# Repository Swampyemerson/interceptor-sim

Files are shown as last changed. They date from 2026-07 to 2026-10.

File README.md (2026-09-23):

# Counter-UAS Interceptor — Sim-Proven Guidance, Real Build In Progress



A quadcopter interceptor that catches a moving target with its own camera.
The **ruled engagement (ADR-0103/0105) is a chase-only pursuit**: cued once
at the trigger by a GPS relay (latched, link dead after launch — **no
datalink in flight**), it flies a belief rendezvous to behind the target and
closes on camera measurements. The earlier **coded open-loop dash +
pro-nav terminal** remains the flying default only until a Gazebo
cross-check passes. Guidance was built and validated across a 107-ADR
measured campaign in **PX4 SITL + Gazebo Harmonic** plus a purpose-built
flight-code-in-the-loop Monte-Carlo simulator; the physical interceptor is
**on the bench** (motors soldered, flight-controller pack verified on-board,
Pi-to-Pixhawk OFFBOARD proven props-off).

<p align="center">
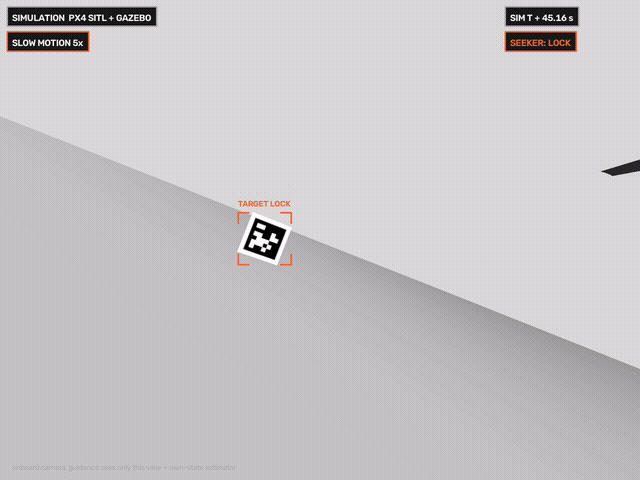
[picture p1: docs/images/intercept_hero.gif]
Onboard seeker view of a simulated intercept, slow-motion terminal, closest approach 0.413 m
  
</p>
<p align="center"><sub>Onboard seeker view, simulation (PX4 SITL + Gazebo). Closest
approach 0.413 m against a 2 m/s crosser; retiming labeled on-screen; the
0.35 m contact bar is still open. Log: <code>logs/m4_intercept_pronav_20260923T025539Z.csv</code>.</sub></p>

**Status at a glance** (each row traces to the contract):

| | |
|---|---|
| Ruled design | chase-only pursuit (ADR-0103/0105); dash + pro-nav stay the flying default — the Gazebo cross-check **failed its registered bar** (below), so the swap is blocked |
| Flight-code port | matches its prototype in the fast sim (100% of 50 nominal runs ≤ 0.35 m, median 0.068 m); in Gazebo it chases camera-driven but closes only to median 1.51 m — **simulation, transfer gap open** |
| Not yet done | no camera-guided intercept inside the 0.35 m contact bar in Gazebo; no real-world intercept |
| Hardware | bench build under way; Pi 5 seeker measured 96.6 fps (AprilTag pipeline) |
| Honesty machinery | ground truth firewalled from guidance (AST-enforced); assumptions register grades every given input |

This is a portfolio project for aerospace internship applications. The claim
discipline is the point: every number below traces to a committed log, a gate
script, or an ADR in [`docs/decisions.md`](docs/decisions.md) — and the
project's retractions are documented with the same care as its wins, because
**the negative results are load-bearing**. The honest resume line:

> *"Camera-only terminal guidance validated by Monte-Carlo miss statistics in
> PX4/Gazebo SITL and a flight-code-in-the-loop simulator; ported the ruled
> pursuit terminal into the flight software to numeric parity with its
> prototype (100% of 50 seeded runs inside the 0.35 m contact radius, median
> 0.068 m, simulation); quantified the perception acquisition envelope and
> the flight-dynamic detector-recall limit."*

<p align="center">
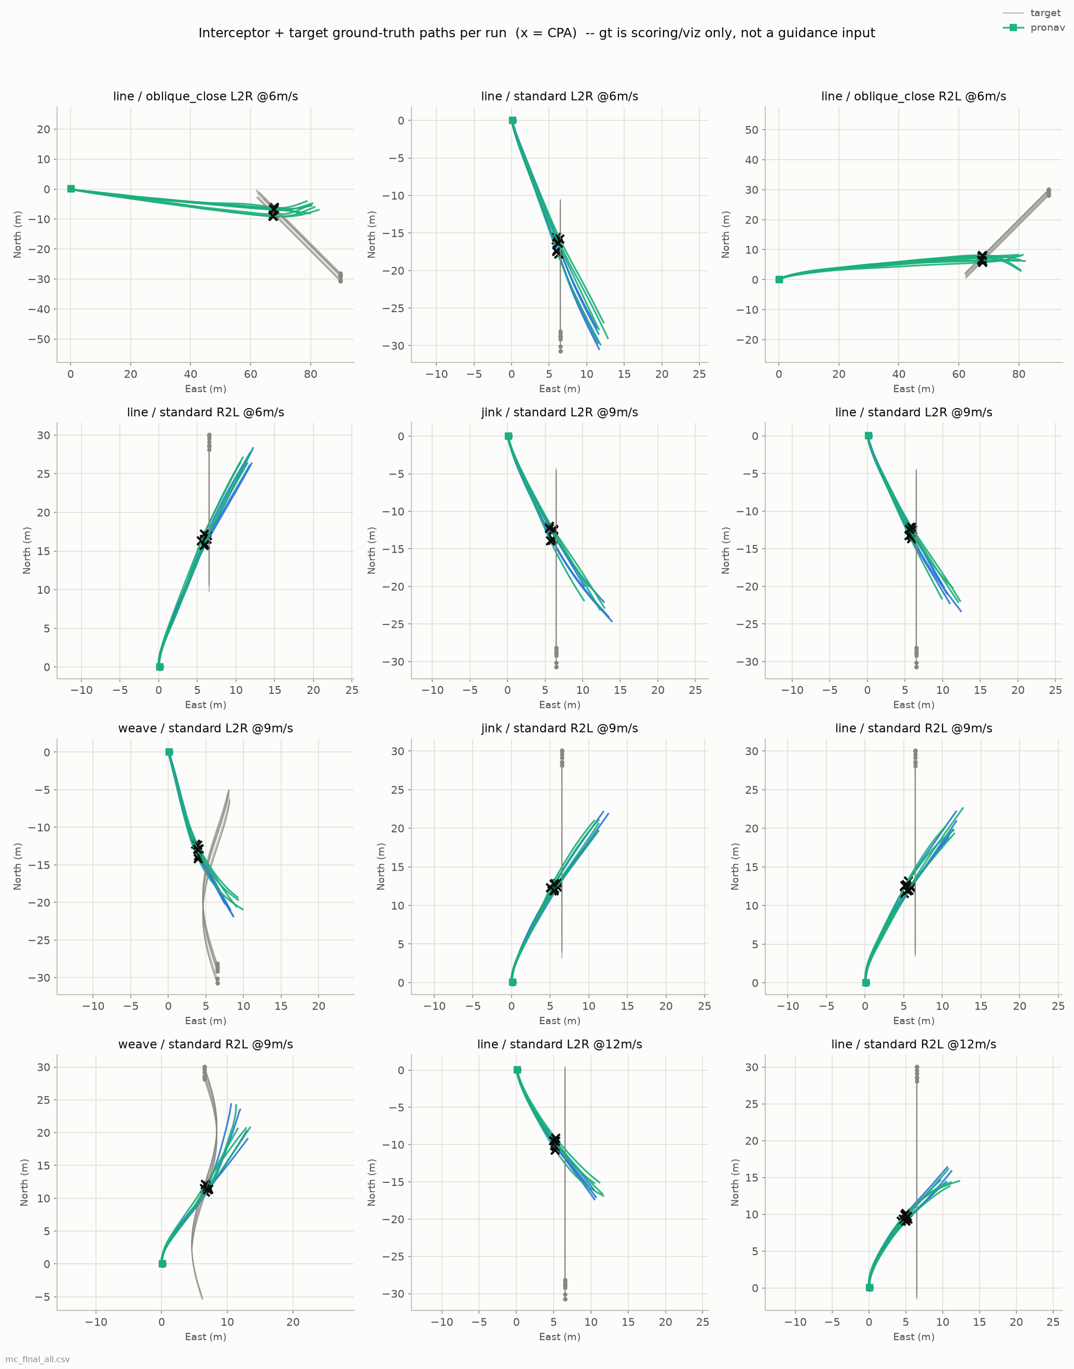
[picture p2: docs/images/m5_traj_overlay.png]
M5 Monte-Carlo trajectory overlay
  
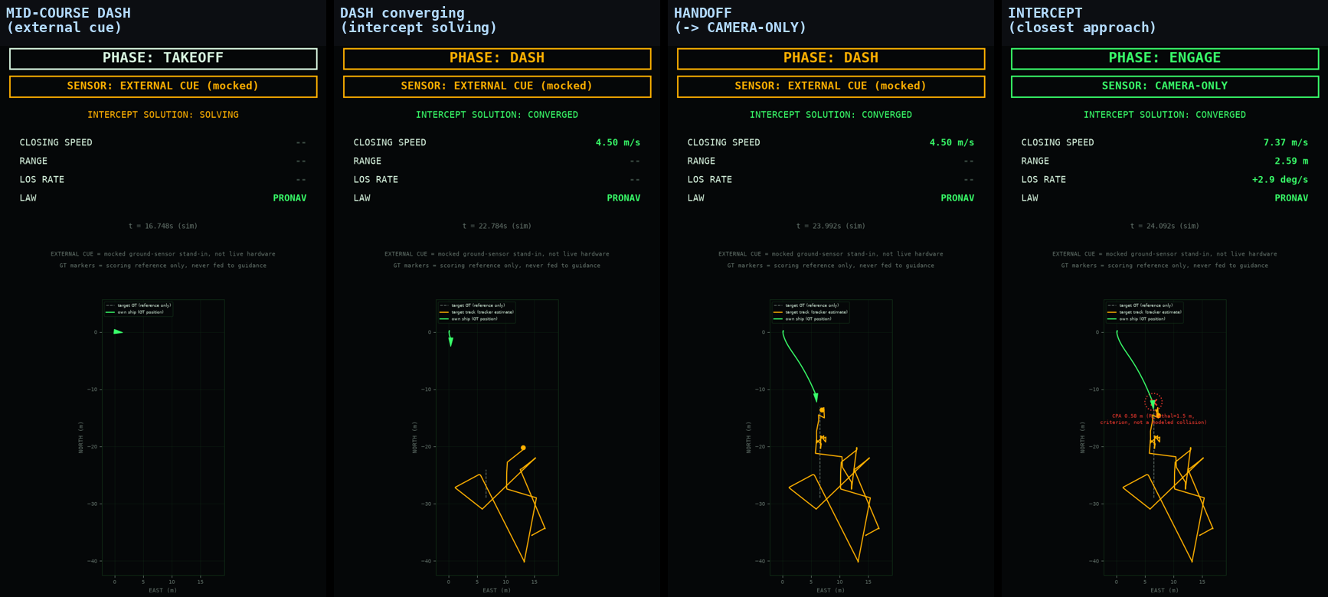
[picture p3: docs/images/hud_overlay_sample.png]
Seeker HUD overlay at handoff
  
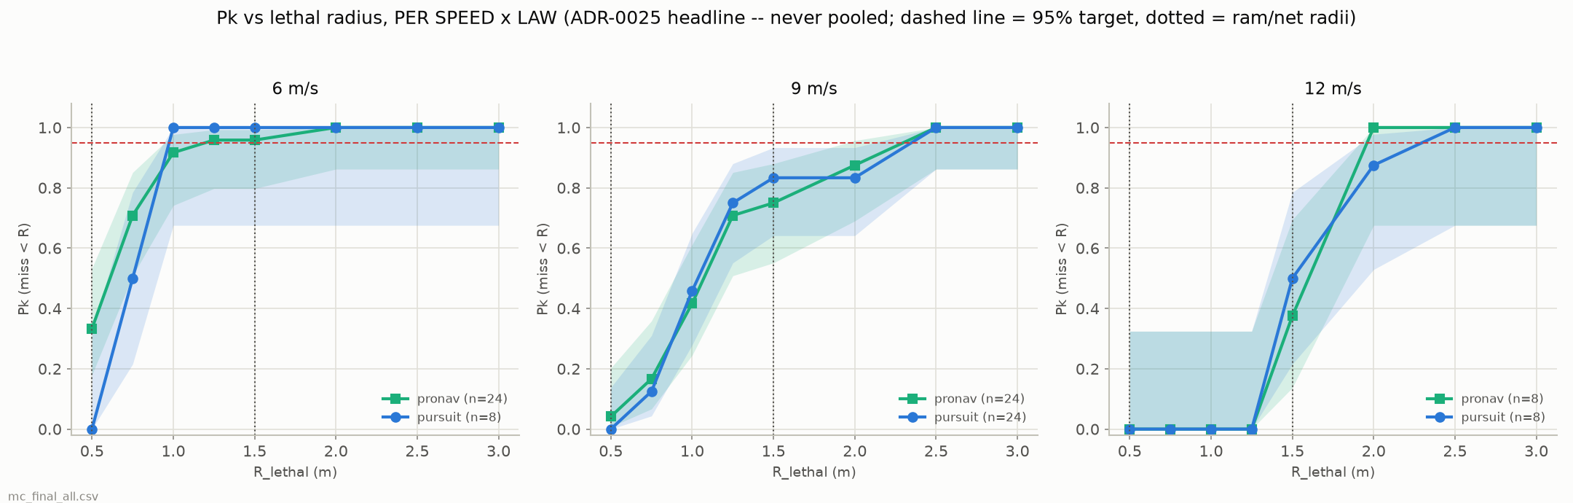
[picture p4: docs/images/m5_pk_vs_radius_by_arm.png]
Pk vs lethal radius, per speed and law
  
</p>

**Canonical live state:** [`docs/project_state.json`](docs/project_state.json)
— the machine-readable contract (stage statuses, hard constraints, a
contradiction ledger, a dead-ideas graveyard, an assumptions register) —
rendered to [`docs/dashboard.html`](docs/dashboard.html) and the generated
MBSE views ([`docs/mbse.html`](docs/mbse.html)). Where anything in this README
and that contract disagree, **the contract wins**. Mission and scope history:
[`docs/goals.md`](docs/goals.md); milestone roll-up:
[`docs/progress.md`](docs/progress.md); working front:
[`docs/next.md`](docs/next.md).

**Read "What is proven / what is not" before the results table.** Several
headline-looking numbers from this project's own history were retracted by
its own audits; this README quotes only what survived. The long form of every
table caveat: [`docs/results_notes.md`](docs/results_notes.md).

---

## Current mission (the real build)

**A cued interceptor hits a moving target flying ≥9 m/s (20 mph), outdoors,
camera-only terminal, no datalink after launch.** The ruled engagement is
chase-only pursuit (ADR-0103/0105); the coded dash + stock pro-nav remain the
flying default only until the Gazebo cross-check passes. Success is a
**binary kill** (contact), confirmed by seeker video + phone slow-motion +
both aircraft flight logs — deliberately *not* a measured sub-meter CPA (the
RTK metrology pair was cut with the 2026-07-15 binary-kill re-scope). The
**first kills fly the AprilTag seeker** (96.6 fps measured on the Pi 5 CPU);
the markerless seeker is the end-state — the real-data retrain `n-mono`
(AP50 0.44 held-out) is the hardware default for that phase, pending the
Hailo NPU, and it never reads the tag. Source: `docs/project_state.json`
(goal), `docs/real_build_coded_dash.md`, `docs/hardware_order_list.md` §0b/§0c.

Hard constraints (full list + evidence in the contract): **no guidance
datalink after launch** (the GPS cue is latched at the trigger and the link
is dead from then on; the RC link is kill/arm only — jam resistance by
architecture, not protocol); **wide FoV (~100°) non-negotiable** (ADR-0024;
the ±30° figure it protected is a dash-era acquisition envelope); **prop
clearance is a geometry problem**, not a software one.

---

## What is proven, and what is not

**Proven (gated, committed evidence):**

- **The guidance law and loop.** Pro-nav (`a = N·Vc·λ̇`, N=5) beats pursuit
  4.6–7.6× on a 2 m/s crosser, camera-only (M4 gate); the two-stage
  dash→camera-terminal architecture holds to 12 m/s maneuvering targets
  against a cooperative (billboard/AprilTag-class) sensor picture. The
  portable [`flight/`](flight/) core (LOS derotation, alpha-beta estimation,
  pro-nav, undistortion, camera lever-arm) is pure math with its own test
  suite and no sim imports — it runs unchanged on the real Pi.
- **The methodology.** Paired seeds (n≥8), control arms, pre-registered
  verdict scripts, a numeric no-cheat audit on every guidance path, and a
  statistics-before-verdicts rule. This machinery caught every false
  positive below *before* it shipped.
- **The chase-only flight-code port.** The ruled pursuit terminal
  (`flight/pursuit_terminal.py`, a relative-state Kalman filter with
  capture-time attitude handling) runs through the unmodified flight state
  machine to **numeric parity with its prototype**: a registered tick-level
  trace found four coupled port defects, and the fixed port scores 100% of
  50 seeded nominal runs inside the 0.35 m contact radius, median 0.068 m
  (`isim/specs/parity_trace_2026-09-22.md`) — **simulation**. The
  pre-registered independent Gazebo cross-check then delivered both kinds of
  result: its shakedown flight caught a fifth port defect (a frozen Phase-A
  camera yaw, invisible to the isim grid, fixed and regression-pinned), and
  the scored n=8 **failed the registered bar** — the port chases
  camera-driven (46–67 detections consumed, zero aborts) but closes only to
  median 1.51 m vs the 0.122 m matched-optics prediction, so the
  default-terminal swap stays blocked and the transfer gap is the named next
  problem (`docs/xcheck_gazebo_pursuit_prereg.md`).

**Not proven — the honest wall (this is the interesting part):**

- **No camera-guided intercept of the realistic 3D quad target exists in the
  dataset.** When the flat billboard target was replaced with a proper 3D
  quad, a series of sub-meter "camera-guided" results were retracted as
  **open-loop dash-ballistics mirages** — a control arm with the camera
  contributing nothing scored the same (dash-only 0.30 m vs with-terminal
  0.29 m; ADR-0076 add #18g/#18h). Five such mirages were caught and
  retracted in that arc alone (ADR-0076; `docs/project_state.json`
  graveyard).
- **The binding wall is flight-dynamic detector recall, not guidance.** The
  deployed markerless detector reads **100% recall statically at 8–22 m**
  but **~0.8% on the approach in flight** (ADR-0076 add #18i/#18k). The
  un-eliminated mechanisms are ground-clutter background under the
  nose-down dash pitch and phantom competition — both sim-testable, both
  open. The dash pitches nose-down ~27–36° (median; ADR-0060), which parks
  a co-altitude target at the top of the frame; the pointing fix is a fixed
  up-tilt mount sized to the *measured* real dash pitch (build item, not
  yet validated).
- **The dash-era terminal had no vertical channel, and its miss was ~82%
  vertical** (ADR-0095/0099/0100): the fix arc moved sprint-only flights
  from 2/16 to 13/16 inside the contact radius — best case only (camera off,
  aim within ~±1° of optimum, target height known to ~0.1 m). The chase-only
  pursuit terminal steers all three axes; its own vertical behavior is what
  the current cross-check exercises. Full forensic history:
  [`docs/vertical_channel_analysis.md`](docs/vertical_channel_analysis.md).
- **"Works comms-denied" stays HELD** — see the box in the results section.

---

## Headline results (each traced; scope stated inline)

| Result | Number | Scope / caveat | Source |
|---|---|---|---|
| M0–M2 foundations (boot, camera, AprilTag detection) | detection rate 1.000, mean pose error 0.0861 m @ ~4.9 m | wide (99.7°) lens; sim lighting | gates `check_m0/1/2.sh`, 2026-07-04; `docs/progress.md` |
| M3 static intercept, hold 2 m standoff | final error **0.018 / 0.035 m** (bar < 0.5 m) | two verifier-confirmed runs | `scripts/check_m3.sh`; ADR-0008; committed `logs/m3_intercept_*.csv` |
| M4 pro-nav vs pursuit, 2.0 m/s crosser, camera-only | pro-nav **0.402 / 0.277 / 0.443 m** vs pursuit **2.544 / 2.109 / 2.048 m** | official gate-config runs; the dev-phase config selection that night is disclosed (ADR-0009 addendum; [notes](docs/results_notes.md#m4)) | `scripts/check_m4.sh`; ADR-0009; committed `logs/m4_intercept_*_20260705T03*.csv` |
| Two-stage handoff (S2), 6 m/s crosser | miss 1.1–2.3 m, handoff latches, honesty audits pass | proves the *architecture* (running start + structural handoff), not sub-meter precision; the S2 ground-stereo architecture is since retired | `retired/scripts/check_s2.sh`; ADR-0010/0013 |
| Why fast crossers miss ~1.4 m (41-flight forensics) | terminal correction capacity **½·a·t_go² ≈ 0.72 m** vs **1.69 m** already delivered at handoff → a perfect terminal camera cuts the miss only ~25% | miss tracks zero-effort-miss at handoff with r² = 0.96 — *variance explained*, not "96% of any one miss" | ADR-0023/0027; `retired/docs/terminal_diagnosis.md` |
| M5 final Monte-Carlo, n=96 (pursuit vs pro-nav × 6/9/12 m/s × line/maneuver/oblique) | **96.9% clean** (ran to completion and engaged; failures stay in every Pk denominator), mean miss 1.08 m, median 0.93 m; per-speed Pk per ADR-0025, never pooled | flew the **clean AprilTag sensor** (the disclosed perception upper bound), flat-board target; laws tied within the ~1 m run-to-run noise ([notes](docs/results_notes.md#m5)) | ADR-0036; `scripts/check_m5.sh`; committed `logs/mc_final_all.csv`; plots `docs/images/m5_*.png` |
| Markerless seeker v2 (kill the AprilTag) | false-detection pollution **0.751 → 0.000**, range honesty **0.056 → 0.935**; ~+1 m median miss vs the tag = bearing *quality* (box-center vs subpixel corners) | in-sim markerless; on real outdoor mono frames v2 scores **AP50 0.0003** (transfer bet lost) — the hardware seeker is the real-data retrain `n-mono` (AP50 0.44 held-out) | ADR-0038/0040/0042/0043; `scripts/check_seeker_v2.sh`; `logs/nn_tier/eval_n-mono_heldout.csv` |
| Chase-only flight-code port parity | port matches prototype: **100% of 50 seeded nominal runs ≤ 0.35 m, median 0.068 m**; aim-error 10°/20° cells 100%; target +2 m cell 68–76% (no-re-approach design gap) | **simulation** (flight-code-in-the-loop isim); a registered trace found and fixed 4+1 port defects — the fifth (a frozen Phase-A camera yaw) was caught by the Gazebo cross-check, invisible to the isim grid | ADR-0103/0105; `isim/specs/parity_trace_2026-09-22.md` |
| Gazebo cross-check of the chase (pre-registered, n=8) | camera-driven chase confirmed (46–67 detections/flight, 0 aborts) but CPA **0.55–2.33 m, median 1.51 m** — registered bar **FAILED**; default swap stays blocked | the honest transfer result: real EKF/control/latency dynamics cost ~1.4 m vs the fast sim's matched prediction (0.122 m); diagnosis next, not tuning | `docs/xcheck_gazebo_pursuit_prereg.md`; `logs/xcheck_gz_20260923_fixed/` |
| Detect-then-track maneuvering terminal (billboard era) | post-handoff camera-terminal Pk@2.5 m: weave **3/16 → 14/14**, jink **1/8 → 14/15** (paired n=16 baseline reads 3/15 → 14/15); phantom handoffs 12 → 0; zero gross (>8 m) false terminal detections (0/155) in the headline arm | one empty Gazebo world (disclosed); **the CSRT tracker was later dropped for the 3D quad target** — the deployed config is NN-only every frame (ADR-0076 add #2; [notes](docs/results_notes.md#t21)) | ADR-0058; committed `logs/mc_t21_*.csv`; `scripts/check_t21.sh` |
| Pk statistics hardening, n=72 | **Pk@2.8 m 72/72 — 95.0% Clopper-Pearson lower bound** (clears the ratified ≥95%-CI bar); Pk@2.5 m 71/72 = 98.6% point / 92.5% CP-LB | **flat-billboard target**, weave + 12 m/s only, never pooled, radius always stated; the 3D-quad target later exposed the wall this shape masked ([notes](docs/results_notes.md#pk72)) | ADR-0064/0025; committed `logs/mc_pk72_weave_s*.csv` |
| Perception wall, quantified | in-flight approach recall **0.8%** vs **100% static** at 8–22 m, same detector, same threshold | the wall is flight-dynamic (pointing + background + phantom competition), **not** range/resolution/aspect — each of those was tested and eliminated | ADR-0076 add #18i/#18k; `scripts/seeker/approach_recall.py` |
| Open-loop dash robustness | 48/48 flights still acquired/engaged with up to **±30° aim error** | dash-robustness only — *not* perception proof (ENGAGE streaks can be phantom, add #18g) | ADR-0076 add #18b/#18c |

> **Comms-denied status: HELD — tested, not merely untested.** The one-way
> handoff latch is real and structural: once the camera terminal latches, the
> cue channel is closed and unreadable, so a link jammed *after* handoff
> cannot touch the terminal. But the flown 8-arm jam Monte-Carlo (ADR-0059)
> showed the cue-era deployment config **fails closed** under a jam
> *before* camera acquisition (real handoffs 12/16 → 2/16 → 0/16 as the jam
> moves earlier — a clean dose-response witness); the staleness fix
> validated **fail-safe, not recovery**, and a dedicated recovery arm was an
> honest NULL (the camera never reacquired at 15–21 m — a perception limit,
> not guidance). So "works comms-denied" is **HELD everywhere in this
> project's materials**. The real build's answer is architectural: the GPS
> cue is **latched at the trigger and the link is dead after launch** — there
> is no in-flight link to jam. That machine has not flown, so nothing is
> claimed for it.

Superseded results (ADR-0028/0030/0031 running-start and degraded-cue
figures, the ADR-0029 hover-geometry regime map, the cue-era fusion numbers)
are kept in `docs/decisions.md` with their supersession notes and are not
quoted here.

---

## Architecture (ruled: chase-only pursuit; flying default: coded dash, pending cross-check)

```
CUE         GPS cue relayed once and LATCHED AT THE TRIGGER (a given input,
            graded in the assumptions register); link dead after launch
   ↓
PHASE A     belief rendezvous: fly to a point behind the believed target,
            match its speed; camera yaws at the believed target
DETECT      AprilTag tag36h11 on every frame (first kills; 96.6 fps measured
            on the Pi 5); markerless n-mono is the end-state seeker
MEASURE     tag box + intrinsics → bearing; box width → range (slant-
            corrected), converted with attitude at frame-CAPTURE time
ESTIMATE    relative-state Kalman filter (position + target velocity);
            delayed-measurement update, coasts dropouts
PHASE B     camera close: v = v̂_target + v_close·LOS + k·(predicted miss);
            a missed pass aborts to SAFE hover (ADR-0107)
ACT         velocity setpoints → PX4 OFFBOARD (MAVSDK), unmodified flight
            state machine (flight/deploy/real_flight.py)
   ↓
KILL        sim: ground truth scoring-only; real: binary kill on video +
            both aircraft logs (contact bar 0.35 m, ADR-0084)
```

The retired sprint-era loop (coded dash → streak handoff → LOS-rate pro-nav,
NN-only detector) remains the **flying default** until the Gazebo cross-check
passes, and is preserved in the contract's stage notes. The portable
[`flight/`](flight/) package has no gz/ground-truth/cue imports (enforced by
AST-based honesty tests) and runs unchanged on the real Pi
(`scripts/check_deploy_sitl.sh`, props-off bench gate passed on hardware).

**Honesty boundary (unchanged since M0):** `gt_*` ground-truth topics are
scoring/logging only; guidance sees camera pixels + own-state EKF, nothing
else. Every gate re-derives the numeric no-cheat check, and
`tests/test_honesty_static.py` / `tests/test_honesty_seekers.py` pin it
statically (AST scans over every live seeker module, mutation-calibrated).

---

## The real build (Tier-1, in progress)

**Status 2026-09-23 — assembly under way.** Motors are soldered to the ESC,
the flight controller's 44-parameter pack is verified on the board (read back
across a reboot), the GPS/compass is talking on GPS1, and the Pi-to-Pixhawk
MAVSDK OFFBOARD link is proven props-off — the one link the simulation never
exercised. Remaining before first power-up: the battery pigtail + continuity
checks, then the smoke-stopper gate (`docs/project_state.json` build_tab).

**Earlier — 2026-08-10 — the hardware measured.** The Pi 5 seeker
rig runs the real camera (1280×800 mono, exposure **994 µs**, inside the ≤1 ms
spec), the flight controller passes **MAVSDK OFFBOARD over a real serial UART with
props off** — the one link the simulation never exercised — and the deployed camera
source was measured **on hardware at 60.27 fps** (114.9 uncapped). Along the way
the seeker was found to have been running at 30 fps purely because nobody had set a
frame-duration limit; lifting it cuts the range burned forming the handoff by about
3.2× (ADR-0090).

> **The scorer measures the wrong point, and the correction is SMALL.** The
> miss-distance scorer ranges to the **camera**, not the airframe centre the kill
> criterion is defined against (ADR-0084). Re-scored properly with a purpose-built
> offline tool, the adopted config moves from **3/16 to 5/16** inside the 0.35 m ram
> radius — the interpolation between logged samples is worth ~0.03–0.06 m and is
> real, but it is a modest correction, not a reversal.
>
> **An earlier version of this note claimed 12/16, and that was wrong.** It rested
> on a figure of "+0.208 m camera lens above the airframe datum", which turned out
> not to be a lever arm at all: it was `gt_cam_z − alt_m`, differencing a *world* z
> against MAVSDK's *relative* altitude, so it measured the **landing gear's height**.
> Three independent routes — the SDF chain, the collision geometry, and the on-pad
> telemetry — put the camera **~2 mm** above the airframe datum and 0.120 m forward
> of it. The real correction is therefore almost entirely **horizontal**.
>
> **So the headline stands: nothing has yet landed inside the ram radius reliably**,
> and the largest remaining term is a **vertical** one (median −0.374 m — the
> interceptor flies low), on a vehicle whose targeting math is explicitly 2-D
> horizontal. That gap is real and unclosed. All of these numbers still assume a
> perfect launch cue, co-altitude flight and no wind. Detail:
> [`docs/rescore_2026-08-10.md`](docs/rescore_2026-08-10.md).

**Earlier — 2026-07-25 — Tier-1 fully ordered** (target-drone stack, seeker
kit, interceptor flight controller, consumables), after the what's-left push
([`retired/docs/audit_2026-07-25_whats_left.md`](retired/docs/audit_2026-07-25_whats_left.md))
closed the desk backlog: the **ram/kill radius ratified at 0.35 m** (ADR-0084 —
the ordered 5-inch pair's contact envelope, so every Pk figure is quoted
against a radius the hardware can actually deliver), the field-day P0s closed,
the print artifacts dimensionally verified, `FAILSAFE 7` and the kill-day
protocol written, and CI brought green. The Tier-1 software layer — Pi 5
session recorder, the two-curve money-gate scorer, binary-kill metrology from
both aircraft logs, the SITL-validated OFFBOARD deploy loop — is adversarially
reviewed. The in-person ladder with its go/no-go money gates lives in
`docs/project_state.json` (`build_plan`) and
[`docs/hardware_order_list.md`](docs/hardware_order_list.md); a gate failure
loops back to the cheapest upstream fix, never forward to more spend.

---

## Methodology (the rules that caught the mirages)

- **Lab ranks, Gazebo decides.** The point-mass guidance lab screens ideas;
  only a Gazebo gate turns a ranking into a conclusion. The lab was wrong in
  the optimistic direction five documented times (PIP, Kalata gains,
  emit-vs-differentiate, fusion coverage, absolute miss).
- **Statistics before verdicts.** Run-to-run noise is ~1 m; single-flight
  deltas below that are noise. A/B claims need paired seeds (n≥8) and
  mechanism evidence, with honest "not significant at this n" language.
- **Anti-mirage rule** (earned, not decorative): any new "win" needs a
  control arm (dash-only / ground-truth-consistent audit), paired seeds, and
  validation on held-out *flights* — never frame-eval, never single-seed.
  This is the rule that caught all five coded-dash mirages.
- **Simulate worse than ideal.** Design numbers carry BEST / EXPECTED /
  WORST-credible tiers; decisions must survive WORST.
- **Sim time, never wall time**, and batches only on an idle machine
  (measured RTF-under-load confound, ADR-0009/0015).
- **The graveyard is binding.** Dead ideas (foveated crop, v3/rebal
  retrains, range-plausibility gates, APN/Kalman-CA-PIP, narrow lens, sim
  pivot, onboard acoustics…) are recorded with the evidence that killed
  them, and are not resurrected without new evidence
  (`docs/project_state.json`).

Known sim-to-real gaps are cataloged, not hidden: no motion blur, no
vibration, no outdoor clutter or lighting in the sim
(`docs/sim_to_real_gaps.md`); the tripod session exists precisely to measure
what the sim cannot.

---

## Systems engineering, generated — not hand-drawn

The system model is **generated from the contract**, and the test suite fails
if the rendered views drift from it — so the model cannot disagree with the
build. `docs/project_state.json` holds ~10 pipeline stages with status and
active version, hard constraints, a contradiction ledger (claims challenged
by evidence, resolved in place), a dead-ideas graveyard, and an assumptions
register that grades every input the system is *given* rather than measures
(`measured` / `given-noisy` / `given-perfect` / `unmeasured`) — a number
computed on a `given-perfect` input is reported as a best-case upper bound,
never as the claim.

<p align="center">
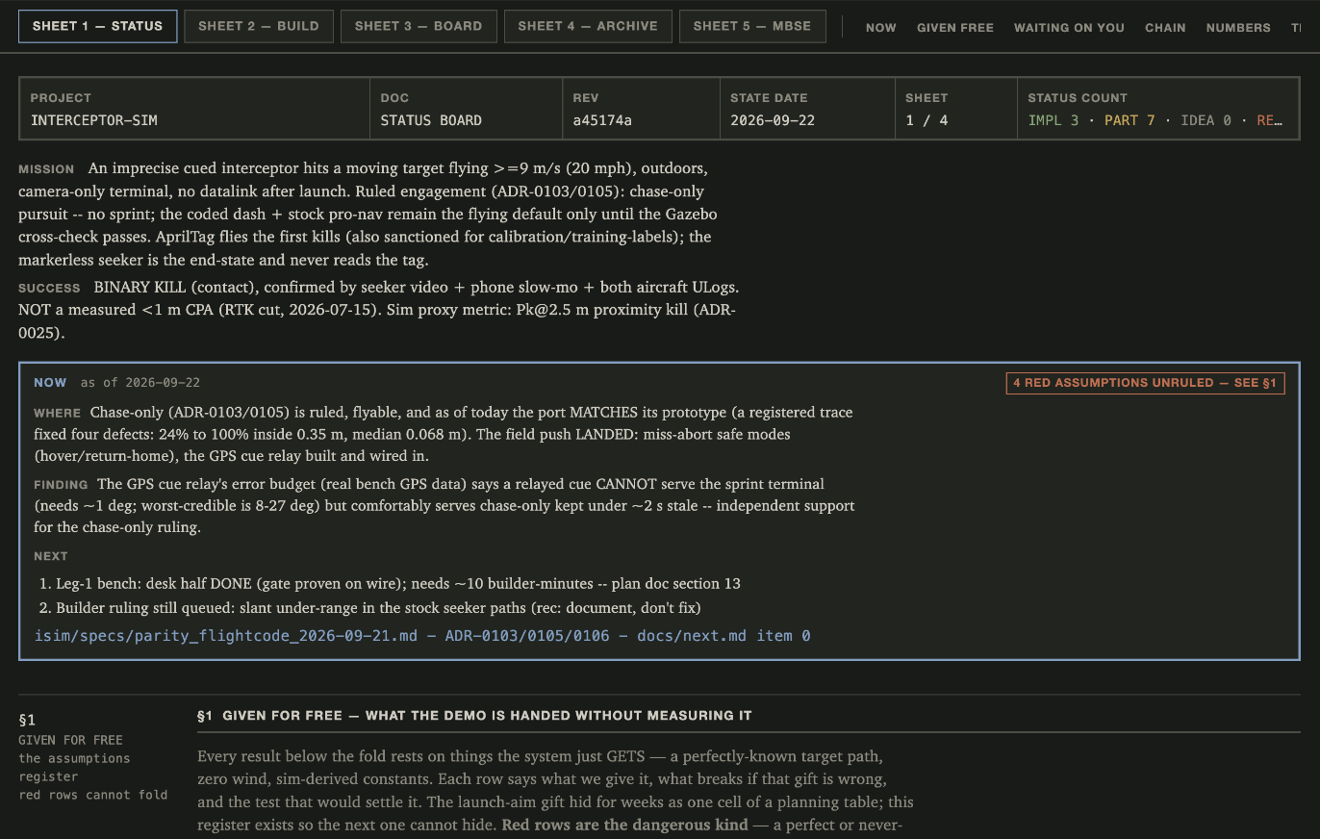
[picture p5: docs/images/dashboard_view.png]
Rendered project status board
  
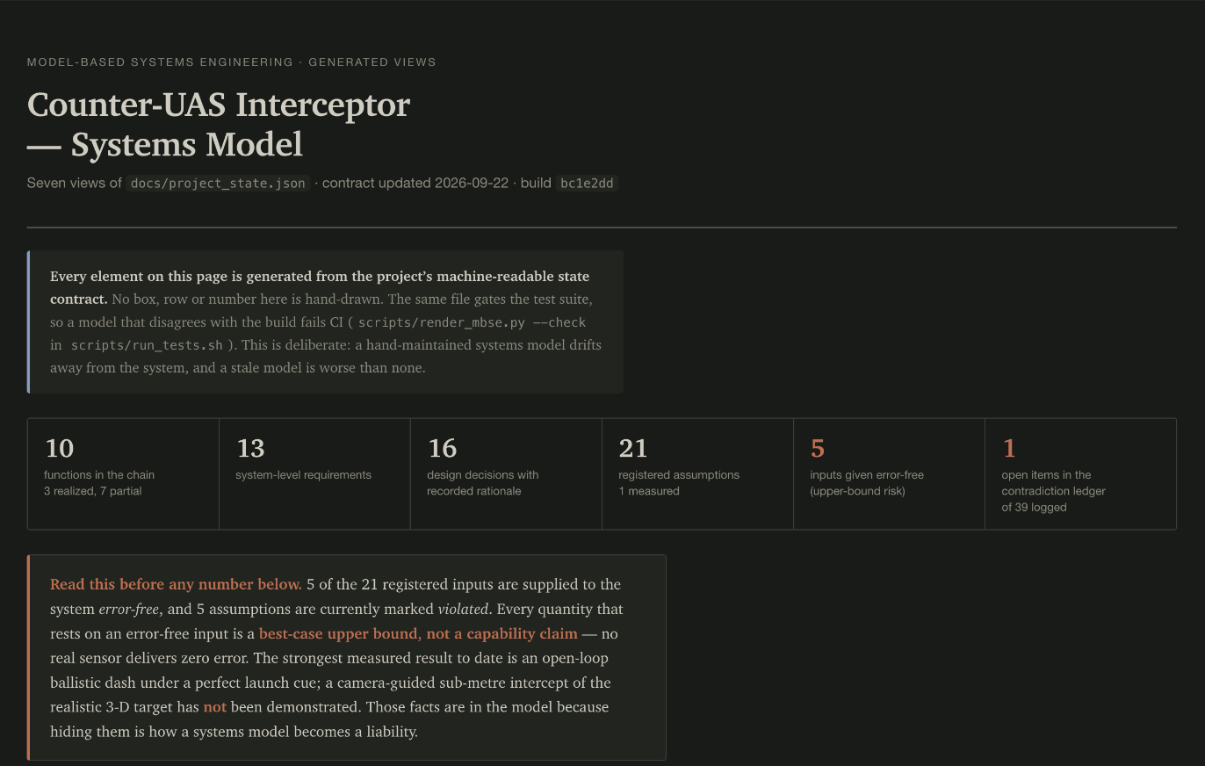
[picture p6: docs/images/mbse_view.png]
Generated MBSE view set
  
</p>

Renderers: [`scripts/render_dashboard.py`](scripts/render_dashboard.py) (the
status board + the drift gate) and
[`scripts/render_mbse.py`](scripts/render_mbse.py) (functions, requirements,
quantities, and their trace links). Views:
[`docs/dashboard.html`](docs/dashboard.html) ·
[`docs/mbse.html`](docs/mbse.html).

---

## Reproduce it

Everything runs headless and writes CSV telemetry to `logs/`. The key
evidence CSVs behind every number quoted above are **committed** (M3/M4
gates, `mc_final_*`, `mc_t21_*`, `mc_pk72_*`, jam-MC and up-tilt arms); bulk
per-run logs are gitignored and regenerable. All Python runs through the
project venv (`.venv/bin/python`).

**60-second check, no sim install** — from a fresh clone, only Python needed:

```bash
python3 -m venv --system-site-packages .venv && .venv/bin/pip install -r requirements.txt
.venv/bin/python -m pytest tests/ flight/tests/  # the offline suite (a few files need the apt gz bindings; CI deselects them when absent)
python3 scripts/render_dashboard.py --check      # the contract/dashboard drift gate (stdlib-only)
scripts/check_t21.sh                             # re-asserts the ADR-0058 headline from committed CSVs
```

**Requirements:** Ubuntu 24.04, PX4-Autopilot (SITL) + Gazebo Harmonic,
Python 3.12, `pip install -r requirements.txt` (plus the apt-installed
`python3-gz-transport13`/`python3-gz-msgs10` bindings — see
`requirements.txt` comments).

**Tests (sim-free, CI-runnable):**

```bash
scripts/run_tests.sh        # offline suite (.venv) + the project-state
                            # dashboard/MBSE drift checks + tool self-tests
```

**Milestone gates** (each a scripted pass/fail, exit 0 = pass; needs the sim
stack): `scripts/check_m0.sh` … `check_m5.sh`, `check_deploy_sitl.sh`
(the retired S1/S2 gates live under `retired/scripts/`). **Monte-Carlo batches** (the evidence machine):
`scripts/mc_batch.sh` + `scripts/mc_analyze.py`.
One sim at a time, idle machine only — batch numbers are only comparable at
matched load. `scripts/env/bootstrap.sh` recreates the config files on a fresh VM; a
normal clone doesn't need it.

---

## Repo map

`flight/` — the portable real-build guidance core + its tests (no sim imports;
runs on the Pi). `scripts/` — sim harnesses, milestone gates, the Monte-Carlo
runner/analyzer, the seeker lane (`seeker/`), the contract renderers.
`worlds/`, `models/` — Gazebo worlds and targets. `docs/` — the contract +
rendered views, the full ADR log (`decisions.md`), design docs, the runbooks.
`logs/` — committed evidence CSVs (everything else gitignored). `tests/` — the
offline suite, including the AST-based honesty pins. `isim/` — the fast
flight-code-in-the-loop Monte-Carlo simulator (vehicle model fitted to 345
logged Gazebo flights). `retired/` — superseded work (S2 ground-stereo, the
T25 demo pipeline, old forensics), kept for provenance, never deleted.

## Built with AI, disclosed

This project was built by the author working with Claude (Anthropic's coding
agent) under the honesty machinery documented above — the AI wrote most of the
code and flew most of the batches; the author set the goals, made the calls,
and asked the questions that caught the biggest overclaims. The process,
including what the AI got wrong along the way, is logged in
[`docs/build_log.md`](docs/build_log.md). Every number still traces to a
committed run or a written derivation; none of the claims rest on the AI's
say-so.

## License

Code and docs: **MIT** (`LICENSE`). The fine-tuned detector **weights are
not in this repo** (gitignored) and carry a separate licensing nuance
(AGPL-3.0 upstream tooling) — see
[`docs/license_notice_weights.md`](docs/license_notice_weights.md) before
redistributing any weights file.

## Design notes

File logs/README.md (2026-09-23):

# logs/ — committed evidence, not scratch

Every file tracked here is a small aggregate CSV/JSON that a published number
traces to (audit finding DEEP-H1: committed so the evidence survives disk
loss). Bulk per-run telemetry is gitignored and regenerable. If a number is
quoted anywhere in this repo, the provenance pointer leads either here, to a
gate script, or to a written derivation.

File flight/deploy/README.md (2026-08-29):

# `flight/deploy` — the real-hardware onboard flight code

Two modules, and the split matters:

| module | what it owns | status |
|---|---|---|
| [`seeker_loop.py`](seeker_loop.py) | the **terminal** only — camera → pro-nav → OFFBOARD setpoint. Deliberately does **not** arm, take off or land. | validated against SITL (`scripts/check_deploy_sitl.sh`) |
| [`real_flight.py`](real_flight.py) | the **flight state machine** that delivers the aircraft to that terminal: `STANDBY → CODED_DASH → ENGAGE → BREAKOFF → SAFE`, with the ELRS GO trigger and every failsafe. | **SKELETON FOR REVIEW — NOT FLIGHT-READY** |

## `real_flight.py` — the onboard flight state machine (skeleton)

Implements `docs/launch_mechanism_plan.md` §5 (build item **L1**): ground takeoff
→ standby hover at the loft altitude on the commanded aim yaw → human trigger on
an ELRS aux channel (arm/kill class, **no target data**) → open-loop coded dash →
camera-only terminal on the 5-detection streak → breakoff → safe.

```bash
.venv/bin/python -m flight.deploy.real_flight --audit      # AST honesty audit,  exits 0/1
.venv/bin/python -m flight.deploy.real_flight --self-test  # pure-logic scenarios, exits 0/1
.venv/bin/python -m flight.deploy.real_flight --dry-run    # fake vehicle + stub seeker, prints transitions
scripts/check_real_flight_sitl.sh                          # the SITL gate (boots PX4, exits 0/1)
```

It **composes** rather than duplicates: the terminal is `seeker_loop.SeekerGuidance`,
the dash aim is `flight.guidance.collision_lead_heading_accel` (ADR-0080), the
speed ramp and loft dive are `dash_forward_speed` / `dash_loft_alt_ref`, and the
handoff streak is contract-identical to the flown `m4_intercept.update_coded_dash_streak`
(pinned by a parity test). The state machine itself is a **pure step function** —
inject a fake vehicle, clock and RC source — so all 47 tests in
`flight/tests/test_real_flight.py` run offline in <1 s.

**Two honesty properties are machine-checked, not promised** (`--audit`, AST not
text): no ground-truth identifier is read anywhere, and the dash heading is
written at **exactly one call site** — the GO edge — after which a second write
raises. That is the enforceable form of "nothing re-steers the dash after
launch" (plan L2 / ADR-lite #5).

**What is NOT ready:** every constant tagged `TODO-BUILDER` in `MissionConfig`
(RC channel map + PWM endpoints, link timeout, altitude/yaw tolerances, dash
speed/accel, all terminal/breakoff ranges), the geofence and kill-switch
interlocks, and the optional trigger-instant bearing latch (default **off** until
bench items L4/L5 land). Do not fly it.

---

# The terminal seeker loop (`seeker_loop.py`)

This is the code the **physical interceptor's Pi 5 will run**. It is the same
camera-only pro-nav terminal the Gazebo sim validates (`scripts/m4_intercept.py`
ENGAGE phase), but wired to **real I/O** and driving the portable, test-pinned
[`flight/`](../) core. Running it on the desk exercises that whole core
end-to-end, so a bug in the frame math, the LOS derotation, the alpha-beta
tracker, or the pro-nav law surfaces **here, on the bench — before it ever costs
a real flight.**

## Pipeline

```
FRAME SOURCE            Picamera2 (Pi) | video file | image dir | synthetic stub
  → ONNX NN DETECT      scripts/seeker/finetuned_seeker.FinetunedNNSeeker  (box)
  → BEARING + RANGE     box centre → flight.camera.CameraModel  (UNDISTORTS)
                        range = fx·span / box_width_px   (span from calib sidecar)
  → LOS AZIMUTH         flight.geometry.derotate_bearing_lambda  (full attitude
                        + fixed mount up-tilt)
  → LEVER-ARM           flight.geometry.camera_to_cg_los  (camera → CG re-anchor)
  → ESTIMATOR           flight.estimator.AlphaBetaFilter  (λ and range channels)
  → PRO-NAV  (N = 5)    flight.guidance.closing_speed + pronav_lateral_accel
  → SETPOINT            NED velocity + absolute yaw → MAVSDK OFFBOARD
                        (`--dry-run` PRINTS the setpoint instead of sending)
```

Every stage is a thin wrapper over an already-tested `flight/` piece. The only
genuinely hardware-specific parts this file adds are **grabbing a frame from a
real camera** and **pushing a setpoint over MAVLink** — both guarded so the desk
path runs without them.

## Honesty / no-cheat boundary (CLAUDE.md #5, ADR-0010)

The loop's **only** inputs are:

1. **camera pixels**, and
2. the flight controller's **own-state EKF** — the body→NED attitude quaternion,
   yaw, and altitude that MAVSDK reports over MAVLink.

There is **no `gt_*`** anywhere in this code (there is no ground truth on real
hardware to read); `grep -n gt_ flight/deploy/seeker_loop.py` returns only the
comments that document this boundary. The `flight/` core it calls is itself
gt-free and test-pinned, and `flight.camera` **undistorts** the target pixel
before any bearing is taken — honesty-critical for the real wide M12 lens, and a
byte-identical no-op for the sim pinhole. The ONNX weights were fine-tuned
**offline** on gt-projected labels (a human-labeler analogue); the **live**
detector at inference is gt-free.

On the **desk** (no flight controller) own-state falls back to a **level hover**
(identity attitude, yaw 0, fixed altitude). That is a benign "assume the camera
is level" stand-in for a bench test — not ground truth.

## Usage

Run everything with the seeker venv (`onnxruntime` + `opencv`):

```bash
# 1) Self-test — synthetic frame → asserts a finite setpoint (no sim/weights/camera)
.venv-seeker/bin/python -m flight.deploy.seeker_loop --self-test        # exits 0/1

# 2) Desk replay over existing captured frames (dry-run PRINTS setpoints)
.venv-seeker/bin/python -m flight.deploy.seeker_loop \
    --source scripts/seeker/data/quad_approach/images \
    --dry-run --mount-tilt-deg 8   # --weights omitted = the n-mono flight default

# 3) Desk replay over a recorded flight video
.venv-seeker/bin/python -m flight.deploy.seeker_loop \
    --source flight.mp4 --dry-run

# 4) On the vehicle — live Pi camera, real PX4 OFFBOARD over MAVLink
.venv-seeker/bin/python -m flight.deploy.seeker_loop \
    --source picamera --mavsdk-url udpin://0.0.0.0:14540 \
    --mount-fwd-m 0.10 --mount-up-m 0.05 --mount-tilt-deg 8
#   ^ NO --weights: the default IS the deployed model. Passing
#     scripts/seeker/weights/drone_finetuned_quad_v2.onnx runs the sim-trained
#     historical bar, which is BLIND on real imagery (AP50 0.0003 / recall 1.1%
#     / false-fire 88.5%, n=4175) -- never fly it.
# add --dry-run to PRINT setpoints instead of commanding the vehicle
```

## Configuration

| Flag | Meaning | Default |
|---|---|---|
| `--source` | image dir · video file · `picamera` | (required unless `--self-test`) |
| `--weights` | ONNX detector | `scripts/seeker/weights/nn_tier/n-mono.onnx` (the REAL-DATA model; sha256 in `weights/DEPLOYED.sha256`) |
| `--intrinsics` | `calibrate_camera.py` / `configs/camera_intrinsics.json` (fx,fy,cx,cy + distortion) | `configs/camera_intrinsics.json` |
| `--mavsdk-url` | MAVLink connect URL; omit for desk dry-run | none |
| `--dry-run` | print setpoints instead of sending | off |
| `--mount-fwd-m` / `--mount-left-m` / `--mount-up-m` | camera lever arm from the CG, body frame (m) | 0.10 / 0 / 0.05 |
| `--mount-tilt-deg` | fixed camera up-tilt of the boresight | 0 |
| `--n-pronav` | pro-nav navigation gain N | 5 |
| `--conf` | detector confidence | 0.25 |
| `--fps` | control-loop rate | 20 |

The **known-size range span** resolves exactly as the sim detector does:
`MARKERLESS_SPAN_M` env → `<weights>.calib.json` sidecar → the config default.
The guidance constants (alpha-beta gains, closing-speed law, velocity clamps,
terminal-coast range) default to the sim's validated **FPV profile**
(`scripts/m4_intercept.py` `FPV{}`, ADR-0010/0011) and live in `GuidanceConfig`.

## Dependencies

- **Required (in `.venv-seeker`):** `numpy`, `opencv`, `onnxruntime`.
- **Guarded (absent on the x86 desk):** `picamera2` (Pi camera) and `mavsdk`
  (MAVLink). The self-test and image/video dry-run paths import neither, so they
  run on this desk unchanged.

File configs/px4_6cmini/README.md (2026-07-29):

# 6C Mini bench pack — props-off Pi ↔ Pixhawk OFFBOARD bring-up

Everything needed to bring up the interceptor's **flight-computer pair** on the
desk — Raspberry Pi 5 talking MAVLink/OFFBOARD to a **Pixhawk 6C Mini** — with
**no airframe, no ESC, no motors** (nothing can spin). This retires the deploy
loop's one link the sim never exercised: `flight/deploy/seeker_loop.py` driving
**MAVSDK OFFBOARD over a real serial UART**.

- Canonical build steps: `docs/project_state.json` → `build_tab` → subsystem
  **`brain`** (steps `brn-01`…`brn-06`; `brn-05` is the gate this pack closes).
- Wiring/param sources: `docs/hardware_order_list.md` **§3** (compatibility) and
  **§B** (RC path). Constraints: `no-datalink`, `honesty-boundary`.

Files here:

| File | What it is |
|---|---|
| `bench.params` | QGC-loadable PX4 parameter file (heavily annotated; every non-default has a WHY + doc source). |
| `README.md` | This procedure. |
| `../../scripts/check_deploy_bench.sh` | The props-off, **no-arm** OFFBOARD check (and its `--check-only` self-test). |

---

## What this bench DOES and does NOT prove

**Proves (props-off, disarmed):** a live heartbeat over the real serial port,
own-state EKF streaming to the Pi **and the own-state stamp advancing for the
whole run** (the only evidence bytes came *back* over the wire), the **OFFBOARD
mode switch accepted while disarmed**, and a **measured** pro-nav setpoint stream
— gated on span ≥ 1 s, mean ≥ 2 Hz and **no inter-setpoint gap ≥ `COM_OF_LOSS_T`
(1 s)** — through the whole `flight/deploy/seeker_loop.py` chain on real I/O.

> **The detector is SYNTHETIC here, on purpose (changed 2026-07-26).** This gate
> certifies a *link*, so its verdict must not be decided by perception. It used
> to run the real ONNX detector over replayed frames, and — measured — the first
> setpoint of a default run came from a **hallucinated detection on a frame with
> no target in it**; on a run without that false fire the same correctly-wired
> hardware produces zero setpoints and prints FAIL. The run now passes
> `--synthetic-detector` (deterministic `SmokeSeeker` + blank frames, nothing
> arms). `BENCH_SYNTHETIC=0` runs the real detector — that is a **perception**
> run and its result does not belong to `brn-05`.

**Not verified here:** the MAVLink **wire** rate. The cadence in the run log is
the rate the Pi *computed* setpoints at; `mavsdk_server` re-sends the last
setpoint on its own timer, so the two are different numbers.

**Deferred to the airframe (NOT here):** arming, motors actually responding to
setpoints, takeoff/land, ESC/DShot, battery monitoring, control-allocation
geometry, MC PID tuning. See the *WAITS FOR THE AIRFRAME* block in `bench.params`.

> **CORRECTED 2026-07-26 — you do NOT need a GPS fix for this bench.** This
> README used to say PX4 would refuse OFFBOARD without an EKF horizontal
> position, so run it outdoors. That is wrong for the **disarmed** case on PX4
> v1.16: a mode change is *always* allowed while disarmed
> ([`UserModeIntention.cpp`](https://github.com/PX4/PX4-Autopilot/blob/v1.16.0/src/modules/commander/UserModeIntention.cpp)
> — "Always allow mode change while disarmed"), and the vehicle code path
> (`seeker_loop.run_mavsdk(smoke=False)`) hard-requires only the EKF **attitude**
> stream, which needs no GPS (missing altitude is a loud warning, not a failure;
> the health/global-position wait lives in the SITL-only `smoke` branch).
> `bench.params` still sets `COM_ARM_WO_GPS=0` — that is an **arming** guard for
> later, not a precondition of this test. **Run brn-05 on the desk.**

---

## Procedure

### 0. Two-rail power (safety first)
Pi 5 on its **own** 27 W USB-C PSU; FC on **USB-C** (or the PM02 pack later).
**Never power the Pi from the FC rail** (two-rail rule, `brn-06`). The 3-wire
TELEM2 link below carries **no +5 V**.

### 1. Flash PX4 on the 6C Mini  (`brn-01`)
Plug the FC into the PC over **USB-C** (data cable). In **QGroundControl** →
*Vehicle Setup → Firmware* → select **PX4 Flight Stack (stable)**. QGC
auto-detects the board as **FMUv6C** and flashes the **`px4_fmu-v6c_default`**
target. (CLI equivalent: `make px4_fmu-v6c_default`.) Insert a **microSD**
(ULogs are the metrology) and confirm QGC shows it.

### 2. First connect + airframe  (over USB-C)
QGC connects automatically over USB. Then *Vehicle Setup → Airframe* → select any
generic multicopter → **Apply & reboot**. Either **Generic Quadcopter**
(`SYS_AUTOSTART = 4001`, *Quadrotor x*) or **Generic Quad + geometry**
(`SYS_AUTOSTART = 5001`, *Quadrotor +*) is fine — with no ESC and no motors the
only difference between them is motor geometry, and both light up the
multicopter control + OFFBOARD stack the plumbing test needs. The **real**
airframe ID / geometry / motors are set when the frame is built.
> **Do the airframe BEFORE loading `bench.params` — this ordering is real, and
> here is the actual mechanism** (verified 2026-07-26, stronger than the vague
> claim this README used to make). QGC's Airframe *Apply* writes `SYS_AUTOSTART`
> **and `SYS_AUTOCONFIG=1`**
> ([`AirframeComponentController::changeAutostart`](https://github.com/mavlink/qgroundcontrol/blob/master/src/AutoPilotPlugins/PX4/AirframeComponentController.cc)),
> and on the next boot PX4 runs
> `param reset_all SYS_AUTOSTART SYS_PARAM_VER RC* CAL_* COM_FLTMODE* LND_FLIGHT* TC_* COM_FLIGHT*`
> ([`rcS`](https://github.com/PX4/PX4-Autopilot/blob/v1.16.0/ROMFS/px4fmu_common/init.d/rcS)).
> Everything in `bench.params` except the `RC_*` line would be **wiped**. That is
> why `SYS_AUTOSTART` is **not** in `bench.params` — and why, **if you ever change
> the airframe later, you must re-load `bench.params` afterwards.**

### 3. Load `bench.params`
*Vehicle Setup → Parameters → Tools → Load from file* → pick
`configs/px4_6cmini/bench.params` → **reboot**. The file carries **10** lines;
all of them were re-verified against **PX4 v1.16** on 2026-07-26 (see the header
block inside the file).

**What QGC should show you.** Modern QGC previews a **diff** before applying and
*skips lines whose value already matches the vehicle*. Four of the ten already
equal the v1.16 defaults, so expect the diff to list roughly these **six**:

| Param | New value | Means |
|---|---|---|
| `MAV_1_CONFIG` | 102 | MAVLink instance 1 → **TELEM 2** |
| `MAV_1_FLOW_CTRL` | 0 | flow control **forced off** (3-wire link) |
| `MAV_1_FORWARD` | 1 | forward Pi↔GCS traffic (bench convenience) |
| `COM_ARM_WO_GPS` | 0 | deny arming when the GPS preflight check fails |
| `CBRK_IO_SAFETY` | 0 | safety button **required** to arm (see below) |
| `SDLOG_MODE` | 2 | log from boot until shutdown |

Silently skipped because they are already the v1.16 default: `MAV_1_MODE`=2,
`SER_TEL2_BAUD`=921600, `COM_KILL_DISARM`=5.0, `RC_MAP_KILL_SW`=0. If QGC
instead reports a param as **not present on the vehicle**, stop and tell the
session — that means a name is wrong for this firmware.

> ⛔ **`CBRK_IO_SAFETY` is new, and it changes what the board will let you do.**
> The v1.16 **compiled default is 22027**, which means the safety-button arming
> gate is **already bypassed** on a stock board — this pack used to claim the
> opposite ("we keep the safety switch active by not setting it"). Setting **0**
> restores the gate, which is the right fail-closed posture for a props-off
> bench. The cost is real: PX4IO advertises the `safety_button` topic even with
> no button wired, so QGC will show a standing *"Preflight Fail: Press safety
> button first"* and **the board will not arm until a safety button is wired and
> pressed.** Nothing about the disarmed OFFBOARD gate changes.
>
> ⚠️ **CORRECTED 2026-07-27 (ADR-0091): this pack used to say the M10 would
> supply that button. The M10 actually in hand has a 6-pin cable — it fits GPS2
> only, and the SAFETY_SWITCH / LED pins are GPS1 pins 6/7, which this module
> does not carry.** So there is no safety button anywhere in the current
> hardware. Harmless here (nothing arms in `brn-05`); at the first props-off ARM
> test either wire a button or set `CBRK_IO_SAFETY` back to 22027 *knowingly*.
> **GPS on GPS2 also needs a param:** set `GPS_1_CONFIG` = **"GPS 2"** (not
> `GPS_2_CONFIG`, which would leave the primary pointed at an empty port) and
> `SER_GPS2_BAUD` = Auto. And the M10's **compass will not appear** — v1.16
> `fmu-v6c` probes the external ist8310 on I2C buses 1 and 4 only, and GPS2's
> I2C is bus 2. See ADR-0091 for the three fixes. If you need a deliberate props-off arm test before the M10 arrives,
> set it back to 22027 *knowingly*, then restore it. Verify on the live board:
> *Parameters → `CBRK_IO_SAFETY`*.

After the reboot, re-open Parameters and confirm the six above. Then
**calibrate sensors** (accel / gyro / mag / level) — sensors-only, bench-safe now.

### 4. Bind ELRS + Radio calibration (SBUS RC in)
Bind the RadioMaster **Pocket** TX to the interceptor's ELRS RX (SBUS output),
wire the RX to the 6C Mini's **dedicated RC IN** pad (not a UART — stock PX4 has
no CRSF driver, §B). QGC *Radio* calibration → then **set `RC_MAP_KILL_SW` by
hand on QGC's *Parameters* page** to the channel your switch actually uses —
Radio calibration does **not** assign it. Flip it and confirm QGC logs *Kill
engaged*, then flip it back and confirm *Kill disengaged*. ELRS is **kill/arm
only** — it carries no guidance (`no-datalink`).

There is no `RC_INPUT_PROTO` to set: the 6C Mini decodes RC in the **PX4IO
co-processor**, which scans SBUS/PPM/DSM in parallel, and that parameter is not
even built into `px4_fmu-v6c`. (`bench.params` §2 has the source citations, and
why writing `0` there would silently *disable* RC on a board that does have it.)

> **`RC_MAP_KILL_SW` is now `0` (unassigned), changed 2026-07-26.** It used to
> carry a guessed `5`. A guessed mapping is not protection, it is the *illusion*
> of protection — and `5` was a bad guess specifically: on ELRS/SBUS, channel 5
> = AUX1 is the conventional **arm** channel, and PX4 reads kill as engaged
> whenever that channel sits above `RC_KILLSWITCH_TH` (v1.16 default **0.75**,
> polarity "true when channel > threshold"). That would have made your first arm
> gesture after binding look like *Kill switch engaged*. **Until you do this
> step, the vehicle has no mapped kill switch** — honest, and harmless while
> nothing can spin.

### 5. Wire the three leads: TELEM2 ↔ Pi  (`brn-03`)

> **⚠️ CORRECTED 2026-07-27 — this heading used to say "three Dupont jumpers",
> which is only true of the PI end and sent the builder looking for somewhere to
> push a jumper into.** **TELEM2 is a JST-GH 1.25 mm 6-pin socket** (the same
> latching type as the GPS plug); a Dupont pin physically cannot enter it. You
> need a **JST-GH 6-pin → Dupont-female cable**, or a spare Holybro 6-pin
> telemetry cable with Dupont females crimped onto three of its wires. The
> **`MAIN` / `AUX` 3-pin `S`/`+`/`−` headers do accept jumpers and must NOT be
> used** — they are the PWM motor outputs (servo signal + a 5 V rail), not a
> UART. And note that **POWER1, TELEM1, TELEM2 and GPS2 are all 6-pin JST-GH**
> and differ only by silkscreen — read the label before it clicks in. Wiring card
> (phone-friendly): https://claude.ai/code/artifact/359e5669-d1f9-4a3d-8327-80f747e7f77d

Both sides are **3.3 V logic — no level shifter**. **TX/RX crossed.** Connect
**only these three** (leave TELEM2 pin-1 +5 V **unconnected**):

| 6C Mini **TELEM2** (JST-GH 6-pin) | → | Raspberry Pi 5 (40-pin header) |
|---|---|---|
| pin 2 **TX** | → | **GPIO15 / RXD**, header **pin 10** |
| pin 3 **RX** | → | **GPIO14 / TXD**, header **pin 8** |
| pin 6 **GND** | → | **GND**, header **pin 6** |
| pin 1 **+5 V** | ✗ | **do NOT connect** (two-rail rule; would fry the GPIO) |

TELEM2 baud = **921600** (`SER_TEL2_BAUD`, set by `bench.params`).

**Free the Pi's serial port** (so it is a data UART, not a login console): on the
Pi, `sudo raspi-config` → *Interface Options → Serial Port* → login shell over
serial **No**, serial hardware **Yes**; ensure `enable_uart=1` in
`/boot/firmware/config.txt`; reboot. The port is **`/dev/ttyAMA0`**.

**Confirm the header orientation on the actual board before pushing anything on** —
run **`pinout`** on the Pi (ships with Pi OS): it prints your board with the 40-pin
header mapped, so which end is pin 1 is observed, not inferred from a drawing.

#### 5a. Making the lead from a spare TELEM↔TELEM cable (2026-07-29)

> **CHECK THE MAIL FIRST.** A ready-made **JST-GH 6-pin → Dupont pigtail is already on
> order** (`docs/hardware_order_list.md` (D); `project_state.json` → `build_tab.brain` →
> "Pi-to-TELEM2 UART jumper leads"). Holybro sell exactly this part. Only hand-make one if
> you want the link closed before it lands — and note that cutting pins 4/5 off a TELEM
> cable is permanent, so this donor can never carry a SiK radio afterwards.
>
> **You need:** iron + solder, ~2 mm heatshrink (adhesive-lined if you have it — do **not**
> substitute tape on the +5 V stub, it unwraps), fine strippers, and a multimeter with DC
> volts + continuity. JST-GH wire is ~28 AWG, hair-fine: strip ~3 mm on the finest notch or
> nick-and-pull with a blade; ordinary cutters sever it.

**This procedure is ordered so that every identification is MEASURED before anything is
cut, and the wire the Pi drives goes on last.** Do not reorder it — an earlier draft of
this section capped the +5 V wire *before* the step that probes it, which made the
verification impossible to perform.

1. **Do not cut yet.**

2. **Find GND by continuity — no power, no colour.** FC **unpowered, USB unplugged**.
   Plug the intact cable into TELEM2. Meter in **continuity**. One probe on the FC's
   **USB connector shell** (chassis ground); touch the other to each wire *at the far
   plug's back face*. Exactly one beeps: that is **pin 6, GND**. Flag it with tape
   **within 10 mm of the plug boot** — pin order is only guaranteed at the boot, and a
   long cable can cross wires mid-run.

   > Probe the **wires**, never inside the 1.25 mm socket. A probe tip in the socket
   > bridges adjacent pins, which is the exact damage this whole section is avoiding.

3. **Find +5 V.** Now power the FC on **USB only**, Pi nowhere near it. Meter in **DC
   volts**, black probe on your flagged GND. One wire reads **≈5 V** — that is **pin 1**.
   Flag it too. You now have both **ends** of the ribbon measured.

   > **PRE-DECLARED NULL — read this before you measure.** If **nothing** reads ~5 V,
   > that is a legitimate outcome and **not** evidence you did anything wrong: the
   > peripheral 5 V is a firmware-enabled, current-limited, over-current-latching switched
   > rail, and whether it is driven on USB-only is **undocumented for this board**. Do not
   > re-cut, do not re-count. Fall back to: pin 1 is the wire at the **opposite ribbon edge
   > from your measured GND** (cross-check: on most Holybro 6-pin cables pin 1 is the lone
   > **red** wire — but all-black and rainbow variants exist, and one distributor warns in
   > writing that red may not be pin 1, so colour is only ever a cross-check, never the
   > anchor).

4. **Count inward from BOTH measured ends and flag the rest.** From pin 1: next is **2 =
   FC TX**, then 3 = FC RX. From pin 6: next in is 5 = RTS, then 4 = CTS. Counting from a
   ribbon **edge** is flip-invariant — turning the cable over swaps which side the edge is
   on but never reverses the sequence, so there is nothing to get wrong here.

   > Both TX (pin 2) and RTS (pin 5) are FC **outputs** and can both read a clean logic
   > level, which is why they are anchored from **opposite measured ends** rather than by
   > voltage. A valid 3.3 V reading is not a TX fingerprint.

5. **Now cut**, keeping the flags on the plug side. Cut near the middle; keep the finished
   lead under ~25 cm (921600 baud on unshielded Dupont prefers short runs).

6. **Terminate the three you keep** (pins 2, 3, 6). Cut three female-to-female Dupont
   jumpers in half — three different colours, because the Pi end is where a mix-up
   happens. **Slide a 20 mm piece of heatshrink onto each JST wire BEFORE you solder: it
   will not go on afterwards, the Dupont housing is too fat to pass through.** Tin both
   ends, lap the strands side by side (not butted end-to-end), solder, cool, slide the
   sleeve over and shrink. **One joint at a time**, so no two bare joints ever sit
   adjacent.

7. **Kill the three you don't.** Cut the **+5 V (pin 1)**, **CTS (4)** and **RTS (5)**
   wires back to ~10 mm from the boot, fold the bare ends back on themselves and seal each
   in its own heatshrink. Short is safer than long: there is then nothing to flop onto the
   Pi header. (Pin 4 is an FC *input* — 5 V onto it is a plausible board-killer, and TELEM
   pins are **not** documented as 5 V tolerant.)

8. **Continuity sweep, unplugged and unpowered.** Unplug the lead from the FC **and**
   unplug the FC's USB — continuity mode injects its own current and means nothing while
   the plug sits in a powered board; even unpowered, the FC's internals give false paths
   between TX/RX/GND. Then sweep **all 15 pairs — every wire against every other,
   including the three capped stubs.** No beep anywhere. The pair that matters most is
   **+5 V against TX, RX or GND**: that one takes out a Pi GPIO or crowbars the FC's 5 V
   rail. A short here is found free with a meter and expensively with smoke.

9. **Strain-relieve, tug-test, label.** Zip-tie or tape the three pigtails together ~20 mm
   behind the joints so any pull lands on the bundle. Then pull each joint firmly. A joint
   that moves now would have failed mid-run and looked like a firmware problem. Flag the
   ends `TX→Pi 10`, `RX→Pi 8`, `GND→Pi 6`, and write `TELEM2 3-wire, no +5 V` on the plug —
   six months from now the flags are the only pinout that exists.

10. **Wire it to the Pi with everything dead.** FC USB out, Pi PSU out, no lights. Run
    `pinout` on the Pi beforehand so you know which corner is pin 1, and note that **the
    GND target (header pin 6) is one pin away from +5 V (header pin 4)** — a one-pin slip
    dumps the Pi's 5 V rail into the FC's ground. Connect **GND first**, then RX, then TX;
    when dismantling later, remove **GND last**. Until GND is joined, the two independently
    powered grounds float relative to each other, so a signal wire landing first puts that
    offset across a 3.3 V input. Never push or pull a Dupont end on a powered header, and
    unplug the JST end **by the housing, never the wires**.

11. **Prove it in two stages — the wire the Pi drives goes last.** With everything off,
    connect **only GND (Pi pin 6) and FC TX (Pi pin 10)**. Two wires, no Pi output
    involved, nothing that can fight. Power up and run §6's byte check — bytes containing
    `fd`/`fe` prove **GND and TX are both correct**. Power down, add the third wire (FC RX
    ← Pi pin 8), and run §6's MAVSDK check: `connected True` proves RX. Each stage has its
    own pass criterion, and a wrong guess at stage one costs nothing.

    > **Precondition:** TELEM2 is only open once `bench.params` is loaded (§3) —
    > `MAV_1_CONFIG=102` is what opens it, and it needs a **reboot**. If the byte check is
    > silent, suspect a skipped §3 or flow control before you suspect your counting.
    > Recovery: shifting the **FC TX** wire to a neighbouring Pi pin is harmless (a wrong
    > 3.3 V pin gives no bytes, not damage). Do **not** brute-force the wire the **Pi**
    > drives — landing Pi pin 8 on the FC's RTS is output fighting output.

12. **Bag the spare half.** It still has a good plug with a **bare +5 V wire** on it. Tape
    its cut ends together, mark it `BARE +5 V`, and put it away — a loose plug with a live
    pin-1 wire is exactly the thing that gets absent-mindedly pushed into TELEM1.

> **Why this is written down.** The pinout tables say "pin 2, pin 3, pin 6" as if the wires
> were labelled. They are not — five of six are typically the same colour, the colour
> convention is vendor discretion rather than standard, and the cable is the one link in
> this chain with no silkscreen, no self-test and no error message. Steps 2–4 exist to turn
> a counted assumption into a measured fact, and step 11 exists because the only test that
> actually proves a serial lead is bytes arriving.
>
> **One forward trap:** if you ever re-apply an airframe in QGC, `MAV_1_FLOW_CTRL` is wiped
> back to auto (§2's mechanism), and this 3-wire lead will stall until `bench.params` is
> re-loaded.

### 6. Heartbeat from the Pi  (`brn-04`)
On the Pi, quick check that MAVLink is flowing (any of):
```bash
# raw bytes moving on the link:
stty -F /dev/ttyAMA0 921600 && timeout 3 cat /dev/ttyAMA0 | xxd | head
# or a MAVSDK heartbeat via the seeker venv (has mavsdk):
.venv-seeker/bin/python -c "import asyncio; from mavsdk import System
async def m():
    d=System(); await d.connect(system_address='serial:///dev/ttyAMA0:921600')
    async for s in d.core.connection_state():
        print('connected', s.is_connected); break
asyncio.run(m())"
```
`connected True` = the companion link is up.

### 7. Props-off OFFBOARD bring-up — the gate  (`brn-05`)
From the repo root **on the Pi** (no GPS fix needed — see the corrected note above):
```bash
scripts/check_deploy_bench.sh
```
It runs the **vehicle** OFFBOARD path (`seeker_loop.run_mavsdk(smoke=False)`) —
connect → own-state → prime setpoint → `offboard.start()` → stream pro-nav
setpoints from replayed frames → clean `offboard.stop()`. **No arm, no takeoff,
no land.** Override the link/source with env vars if needed, e.g.:
```bash
# USB fallback from the laptop (FC on USB-C shows as /dev/ttyACM0):
BENCH_DEVICE=/dev/ttyACM0 scripts/check_deploy_bench.sh
# the REAL detector over replayed frames (a perception run, not the link gate):
BENCH_SYNTHETIC=0 scripts/check_deploy_bench.sh
# ...or over the live Pi camera:
BENCH_SYNTHETIC=0 BENCH_SOURCE=picamera scripts/check_deploy_bench.sh
```

> ⚠️ **The USB fallback does NOT close `brn-05`.** `/dev/ttyACM0` is PX4's **USB
> CDC-ACM** MAVLink instance, started by `rcS`/`cdcacm_autostart` with its own
> arguments: `MAV_1_CONFIG`, `MAV_1_FLOW_CTRL` and `SER_TEL2_BAUD` are **not on
> that code path**, `BENCH_BAUD` is meaningless on CDC-ACM (which is why the
> old `BENCH_BAUD=57600` in this example has been dropped — it never applied),
> and the 3-wire **floating-CTS** failure mode `MAV_1_FLOW_CTRL=0` exists to
> prevent is unreachable. The script now says so itself: it classifies the
> endpoint and prints **`PARTIAL … brn-05 REMAINS OPEN` and exits 3** for
> anything that is not the TELEM2 UART, so a clean USB run can never be absorbed
> as a green gate.

**Exercise the kill switch by hand** during the run — but note it is **half
deferred**:

- **The switch is UNMAPPED until you do step 4.** QGC *Radio* calibration does
  not assign `RC_MAP_KILL_SW`; you set it on QGC's *Parameters* page.
- **What you CAN observe here (disarmed):** QGC's messages panel shows `Kill
  engaged` / `Kill disengaged`, and `actuator_armed.manual_lockdown` toggles in
  the ULog (that field is named `actuator_armed.kill` on PX4 v1.17+). That is the
  whole switch→FC path, and it is what this step certifies.
- **What you CANNOT observe here:** the `COM_KILL_DISARM` auto-disarm. PX4
  v1.16.0 `Commander::handleAutoDisarm()` runs that block only inside
  `if (isArmed())`, so on a never-armed bench it is **structurally unreachable**.
  It is deferred to the first props-off **arm** test on the real frame. Expected
  evidence for *this* run is therefore a ULog with `manual_lockdown` transitions
  and **no** disarm record — the absence is the PASS, not a gap.
- **Flip the switch back** and confirm `Kill disengaged` before moving on:
  `manual_lockdown` latches, and a latched lockdown carried forward will make the
  later arm test refuse for no visible reason.

### Expected output (PASS)
```
[check_deploy_bench] REAL bench run (props-off, NO arm) against serial:///dev/ttyAMA0:921600
[mavsdk] connecting serial:///dev/ttyAMA0:921600 ...
[mavsdk] connected
[mavsdk] armed=False confirmed (--require-disarmed)
[mavsdk] OFFBOARD active; streaming setpoints ...
[mavsdk] stream complete (--max-frames bound reached (300)): 300 frames, 300 detections, 300 setpoints over 15.0s wall, mean cadence ~20 Hz, max inter-setpoint gap 0.05s, max own_age 0.02s, first lock frame #0 synth00000 (queued to MAVSDK)
[mavsdk] offboard stopped
[mavsdk] done rc=0
[check_deploy_bench] PASS (TELEM2 UART -- connect + own-state round trip + OFFBOARD
[check_deploy_bench]   accepted + a measured setpoint stream, disarmed. brn-05 satisfied;
[check_deploy_bench]   perception NOT exercised by design; see logs/deploy_seeker_bench_*.log)
```
`max own_age` is the number `brn-05` exists to measure — it is what will size
`GuidanceConfig.own_state_max_age_s`, which is deliberately unset until then.
Evidence: the run log under `logs/deploy_seeker_bench_*.log` **and** the FC's ULog
on the microSD (logged from boot, `SDLOG_MODE=2`).

**If it fails, in likelihood order (v1.16-corrected 2026-07-26):**

1. **Nothing on the wire at all** (`connected` never prints) → wrong device node,
   TX/RX not crossed, Pi login console still holding the port, or baud mismatch.
   Check the node first: on a Pi 5 the GPIO14/15 UART is `/dev/ttyAMA0`, and
   `ls -l /dev/serial0` should point at it — use whichever the symlink resolves to.
2. **Connects but nothing streams / stalls ~0.5 s at a time** → hardware flow
   control. This is why `bench.params` now sets `MAV_1_FLOW_CTRL=0`: the default
   (`2` = auto) opens TELEM2 **with** CTS/RTS enabled and only drops it after the
   TX buffer backs up with no successful write for >500 ms, and our 3-wire link
   leaves CTS floating. If you skipped that line, set it by hand and reboot.
3. **`own-state EKF ATTITUDE did not stream`** → the companion link is one-way
   (RX not landing on the FC) or the airframe was never applied, so no estimator
   is running.
4. `offboard.start()` rejected → **not** a GPS problem on this bench (see the
   corrected note at the top); look for the FC rejecting the mode in QGC's
   messages panel.
5. Connects and OFFBOARD goes active, then **`0 frames, 0 setpoints`** → the
   frame **source**, not the link. This can only happen with `BENCH_SYNTHETIC=0`;
   check the `detector:` line in the run-log header and any OpenCV
   `imread_(...): can't open/read file` warning just above. A missing
   `BENCH_SOURCE` is now caught *before* the serial port is opened (exit 2, "This
   is a CONFIG problem, not a link problem").
6. **`--require-disarmed and the FC is ARMED`** → something armed the vehicle
   (an RC bind, a leftover QGC arm). Disarm it; the gate refuses to stream
   velocity setpoints into an armed FC rather than trusting the props-off note.

At the *end* of the run, PX4 will notice the setpoint stream stopped
(`COM_OF_LOSS_T` = 1 s) and fall back per `COM_OBL_RC_ACT` (Position mode).
While disarmed that is a no-op mode change — a benign QGC message, **not** a
failure of the gate.

---

## Desk self-test (no hardware)
Validates this pack's own plumbing + that every referenced file exists + that
`bench.params` parses — exits 0/1, touches no hardware:
```bash
scripts/check_deploy_bench.sh --check-only
```

---

## Sources

**Pinned to v1.16** — the firmware actually on the board. `main` docs can and do
differ; every semantic claim above was re-checked at v1.16 on 2026-07-26.

- [PX4 v1.16 Parameter Reference](https://docs.px4.io/v1.16/en/advanced_config/parameter_reference.html) — the enum values for **every** line in `bench.params` (`MAV_1_CONFIG` 102 = TELEM 2, `MAV_1_MODE` 2 = Onboard, `MAV_1_FLOW_CTRL` 0 = Force off, `SER_TEL2_BAUD` 921600, `RC_MAP_KILL_SW` 0 = Unassigned, `RC_KILLSWITCH_TH` 0.75, `COM_KILL_DISARM` 5.0 s default, `COM_ARM_WO_GPS` 0 = Deny arming, `SDLOG_MODE` 2 = from boot until shutdown).
- [PX4 v1.16 Serial Port Configuration](https://docs.px4.io/v1.16/en/peripherals/serial_configuration) — `MAV_1_CONFIG`, `SER_TEL2_BAUD`.
- [PX4 v1.16 MAVLink Peripherals (companion)](https://docs.px4.io/v1.16/en/peripherals/mavlink_peripherals) — recommended companion set: `MAV_1_CONFIG`=TELEM2, `MAV_1_MODE`=Onboard, `MAV_1_RATE`=0, `MAV_1_FORWARD`=Disabled, `SER_TEL2_BAUD`=921600.
- [PX4 v1.16 Raspberry Pi Companion](https://docs.px4.io/v1.16/en/companion_computer/pixhawk_rpi) — TELEM2↔Pi GPIO14/15 wiring, TX/RX crossed, `/dev/ttyAMA0`.
- [PX4 v1.16 Arm/Disarm/Prearm](https://docs.px4.io/v1.16/en/advanced_config/prearm_arm_disarm) — kill switch, safety switch / `CBRK_IO_SAFETY`. **The polarity claim in this pack comes from the source, not this page:** `circuit_breaker_params.c` (default **22027** = bypassed), `Safety.cpp` (`_safety_off = true` when the breaker is set), `systemCheck.cpp` ("Press safety button first"), `ButtonPublisher.cpp` (advertises `safety_button` unconditionally), `Commander.cpp` `handleAutoDisarm()` (kill auto-disarm is **armed-only**), all at v1.16.0.
- [Holybro Pixhawk 6C Mini (PX4 v1.16)](https://docs.px4.io/v1.16/en/flight_controller/pixhawk6c_mini) — `px4_fmu-v6c_default`, **UART5 = /dev/ttyS3 = TELEM2**, dedicated SBUS/DSM/CPPM RC IN.
- v1.16.0 source, for the four behaviours the docs do not spell out:
  [`UserModeIntention.cpp`](https://github.com/PX4/PX4-Autopilot/blob/v1.16.0/src/modules/commander/UserModeIntention.cpp) (mode change always allowed while disarmed),
  [`failsafe/framework.cpp`](https://github.com/PX4/PX4-Autopilot/blob/v1.16.0/src/modules/commander/failsafe/framework.cpp) (no failsafe action while disarmed),
  [`rc_update.cpp`](https://github.com/PX4/PX4-Autopilot/blob/v1.16.0/src/modules/rc_update/rc_update.cpp) (switch states published only while RC is present + updating),
  [`mavlink_main.cpp`](https://github.com/PX4/PX4-Autopilot/blob/v1.16.0/src/modules/mavlink/mavlink_main.cpp) (Onboard-mode stream set; flow-control auto starts ON and falls back after >500 ms).
- Project: `docs/hardware_order_list.md` §3/§B, `docs/project_state.json` (`build_tab.brain`).

> **Card source now lives in the repo:** `configs/px4_6cmini/wiring_card.html` (published to the
> URL above). Edit and republish them together — a bench surface that drifts from this pack is
> the surface the builder actually reads with an iron in his hand.

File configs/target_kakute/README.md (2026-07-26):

# Target-drone config pack — Kakute H7 (ArduCopter mover)

Engineer's notebook for the **target / practice quad** — the drone that flies the
scripted AUTO box/line for the tripod field test (`docs/tripod_test_protocol.md`).
Everything here is prep done **before** the hardware arrives so build day is
assembly + copy-paste, not research.

- **Hardware (ORDERED 2026-07-20, `docs/project_state.json` `bom_tiers[0]`):**
  Holybro **Kakute H7 V1.5** FC · Tekko32 F4 Metal 65A 4-in-1 ESC · EMAX ECOII
  2207 1900KV ×4 · TBS Source One V6 5" frame · Matek M10Q-5883 GPS+compass ·
  RadioMaster **RP1 V2** ELRS nano RX (wired **CRSF**) · RadioMaster **Pocket M2**
  ELRS TX · CNHL 6S 1500 mAh.
- **Files in this pack:** `target.param` (annotated ArduCopter params),
  `gen_tripod_mission.py` (emits the `.waypoints` AUTO mission), `lint_param.py`
  (param-file linter), `selftest.sh` (the offline gate — run it, it must exit 0).
- **Role:** MOVER only. It is not the interceptor and carries no seeker.

> ⚠️ Board name is **`KakuteH7`** (the V1 target), **not** `KakuteH7v2`, and not
> the `-bdshot`/`-Wing` variants. The ordered board is the V1.5 which runs the
> `KakuteH7` firmware. Source: [Holybro Kakute H7 — Copter docs](https://ardupilot.org/copter/docs/common-holybro-kakuteh7.html).

> ⚠️ **DECISION TO MAKE FIRST — "two aircraft, one TX"** (`docs/hardware_order_list.md`
> §0b). One ELRS TX + both receivers on the same bind phrase needs Model Match,
> and then the *unselected* aircraft is in RC failsafe (no independent kill).
> `target.param` ships **OPTION A** (continue-in-AUTO + tight geofence); switch to
> **OPTION B** (plain RTL) if you fly the target as the *selected*, kill-live
> aircraft. See the FAILSAFE block in `target.param`. This changes how you fly, so
> settle it before the field.

---

## 0. Bench safety (every step below is PROPS OFF)

Do **all** of steps 1–8 with **propellers removed**. Props go on only at step 9,
after the kill switch and motor directions are verified. Wear ANSI Z87 glasses any
time a pack is plugged in. Source: [Arming the motors — safety](https://ardupilot.org/copter/docs/arming_the_motors.html).

---

## 1. Betaflight OUT → ArduPilot IN (flash the Kakute)

The Kakute H7 ships with Betaflight. ArduPilot is loaded onto these FPV-style
("ChibiOS-only") boards over **DFU**, once — after that, updates use the normal
Mission Planner path.

1. Install **Mission Planner** (Windows) and, for the first DFU flash,
   **STM32CubeProgrammer** (installs the DFU USB driver). Source:
   [Loading Firmware onto boards without existing ArduPilot firmware](https://ardupilot.org/copter/docs/common-loading-firmware-onto-chibios-only-boards.html).
2. Download `arducopter_with_bl.hex` for board **`KakuteH7`** from
   [firmware.ardupilot.org/Copter/**stable-4.7.0**/KakuteH7/](https://firmware.ardupilot.org/Copter/stable-4.7.0/KakuteH7/).
   The `_with_bl` build includes the bootloader — needed for the first DFU flash.
   Source: same page.

   > ⛔ **Flash 4.7.0 specifically — `target.param` is pinned to it.** "Latest
   > stable" is not good enough here: ArduPilot **renamed five** of the params
   > this pack sets (`GPS_TYPE`→`GPS1_TYPE` in 4.6; `WPNAV_SPEED`→`WP_SPD`,
   > `WPNAV_ACCEL`→`WP_ACC`, `ANGLE_MAX`→`ATC_ANGLE_MAX`,
   > `ARMING_CHECK`→`ARMING_SKIPCHK` in 4.7), **three of them also changed
   > units** (cm/s → m/s, centidegrees → degrees) and one **inverted its sense**.
   > Mission Planner *skips* an unknown name with a warning instead of failing,
   > so loading this file on 4.5/4.6 silently drops those lines. `lint_param.py`
   > enforces the 4.7 spellings; if you must use another release, fix both the
   > file and the linter's `REQUIRED` list first. (Verified 2026-07-26 against
   > `firmware-version.txt` = `4.7.0` and the ArduPilot source at tag
   > `Copter-4.7.0`.)
   >
   > **After loading, read the params back off the FC and diff them against the
   > file.** A dropped write is invisible in the write direction.
3. Put the board in **DFU**: hold the FC's BOOT button (or bridge the BOOT pads),
   plug USB, release. Source: same page.
4. In **STM32CubeProgrammer** select the **USB / DFU** interface → **Open file** →
   the `arducopter_with_bl.hex` → **Download**. Source: same page.
5. Reboot. From now on Mission Planner connects normally and future updates use
   *Setup → Install Firmware* like a Pixhawk. Source: same page.

> If Mission Planner already sees the board over USB, you can instead use
> *Setup → Install Firmware → Load custom firmware* and pick the `KakuteH7`
> `arducopter.apj`. DFU above is the guaranteed first-time path.

---

## 2. First connect + microSD (REQUIRED for the log)

1. Connect the board to Mission Planner over USB (it enumerates as a COM port).
2. **Insert a microSD card into the Kakute** *before* flying. ArduCopter writes the
   DataFlash `.BIN` flight log to this card — and that log is the **scored evidence**
   the tripod test needs (`scripts/field_score.py` reads its `POS`/`GPS` messages).
   **No card = no target track = no scorable pass.** The Kakute H7 has an onboard
   microSD slot for logging. Source:
   [Kakute H7 — Copter docs (logging)](https://ardupilot.org/copter/docs/common-holybro-kakuteh7.html)
   · [Logging / LOG_BITMASK](https://ardupilot.org/copter/docs/common-logs.html).

---

## 3. Bind the RP1 V2 receiver to the Pocket M2 (as **model 1**)

The RP1 V2 talks **CRSF** to the FC (full-duplex UART — this is why `target.param`
sets `BRD_ALT_CONFIG=1` to move RC onto USART6; see §5).

**Wiring (CRSF, cross TX↔RX):**
| RP1 V2 pad | → Kakute H7 pad | Note |
|---|---|---|
| RX **TX** (CRSF out) | **R6** (USART6 RX) | receiver transmits to the FC |
| RX **RX** (CRSF in)  | **T6** (USART6 TX) | FC transmits to the receiver |
| 5V | 5V | |
| GND | GND | |

Source: CRSF is full-duplex and needs both wires + a UART —
[Crossfire & ELRS RC Systems](https://ardupilot.org/copter/docs/common-tbs-rc.html)
· [Kakute H7 CRSF note](https://ardupilot.org/copter/docs/common-holybro-kakuteh7.html).

**Bind:**
1. Flash the **RP1 V2** with an ExpressLRS version whose **major** matches the
   Pocket M2's internal ELRS, and set the **same binding phrase** on both. Source:
   [Binding ExpressLRS](https://www.expresslrs.org/quick-start/binding/).
2. On the Pocket M2 (non-touch radio): **SYS → Tools → ExpressLRS → [Bind]**.
   Receiver LED goes solid when bound. Source:
   [RadioMaster — How to bind an ExpressLRS](https://radiomasterrc.freshdesk.com/support/solutions/articles/64000308598-how-to-bind-an-expresslrs).
3. Create/name this as **Model 1 = "TARGET"** in the Pocket's model list. When you
   later add the interceptor as Model 2, use **Model Match** (unique CRSF receiver
   number per model) so one aircraft can never answer the other's sticks. Source:
   [ExpressLRS Model Matching](https://www.expresslrs.org/software/model-config-match/).

---

## 4. Radio (stick) calibration

*Setup → Mandatory Hardware → Radio Calibration.* Move all sticks + switches to
extremes so ArduPilot learns the endpoints. Set channel reversals here if any axis
is backwards. Source:
[Radio Control Calibration](https://ardupilot.org/copter/docs/common-radio-control-calibration.html).

---

## 5. Upload `target.param`

1. *Config → Full Parameter List* (or *Full Parameter Tree*).
2. **Load from file** → pick `configs/target_kakute/target.param` → **Write Params**.
3. **Reboot the FC.** `BATT_MONITOR`, `BRD_ALT_CONFIG`, and the SERIAL protocol
   changes only take effect after a reboot. Source:
   [Kakute H7 — Battery Monitor / RC note](https://ardupilot.org/copter/docs/common-holybro-kakuteh7.html).

What the file sets (each param is annotated inline with its ArduPilot doc source):
- **CRSF RC** on SERIAL6 via `BRD_ALT_CONFIG=1`, `SERIAL6_PROTOCOL=23`, `RSSI_TYPE=3`.
- **Tekko32 DShot600** (`MOT_PWM_TYPE=6`, `SERVO_BLH_AUTO=1`).
- **Battery monitor** for the onboard V + ESC current sense (`BATT_MONITOR=4`, pins/scales).
- **DataFlash logging** with `POS`+`GPS` for `field_score.py` (`LOG_BITMASK=176126`,
  `LOG_FILE_DSRMROT=1` → one `.BIN` per flight).
- **`WPNAV_SPEED=1000`** (10 m/s) so the AUTO legs clear the protocol's ≥9 m/s.
- **Sane failsafes** (battery low/critical, RC failsafe, geofence) + the §0b
  two-aircraft OPTION A/B blocks.
- **`ARMING_CHECK=1`** — all pre-arm checks left ON.
- **Flight-mode + kill-switch mapping** (see §6).

> After writing, run the linter locally to confirm the file you loaded is the one
> that passes the gate: `python3 lint_param.py target.param`.

---

## 6. Flight-mode switch mapping (incl. the **AUTO** position)

`target.param` sets the mode switch on **RC channel 5** (`FLTMODE_CH=5`) with:

| Switch pos | `FLTMODEn` | Mode | Use |
|---|---|---|---|
| 1 | `FLTMODE1=0` | **Stabilize** | manual fallback |
| 2 | `FLTMODE2=2` | **AltHold** | manual, height held |
| 3 | `FLTMODE3=5` | **Loiter** | GPS hold — **take off / land here** |
| 4 | `FLTMODE4=5` | **Loiter** | (same; spare detent) |
| 5 | `FLTMODE5=6` | **RTL** | manual bail-out |
| 6 | `FLTMODE6=3` | **Auto** | **runs the tripod mission** |

To fly a pass: take off and stabilize in **Loiter** (pos 3), confirm GPS 3D fix +
good HDOP, then flip the switch to **Auto** (pos 6) to run the loaded mission.
Assign the 3-pos + 2-pos switches on the Pocket M2 to produce these six channel-5
values (EdgeTX mixer). Source:
[Flight Modes / FLTMODE_CH](https://ardupilot.org/copter/docs/flight-modes.html).

**Kill:** `RC6_OPTION=31` maps **channel 6** to **Motor Emergency Stop** — the
target's independent RC kill. Assign a channel-6 switch on the Pocket. Source:
[Auxiliary function switches (RCx_OPTION 31)](https://ardupilot.org/copter/docs/channel-7-and-8-options.html).

---

## 7. Sensor calibration

1. **Accelerometer** — *Setup → Mandatory Hardware → Accel Calibration.* Place the
   board level, on each side, nose up/down, inverted as prompted. Source:
   [Accelerometer Calibration](https://ardupilot.org/copter/docs/common-accelerometer-calibration.html).
2. **Compass** (Matek M10Q-5883 external mag) — *Setup → Mandatory Hardware →
   Compass.* Do the onboard/large-vehicle dance until it passes; set the mag's
   mounting orientation if the GPS mast faces off-nose. Fly away from rebar/vehicles.
   Source: [Compass Calibration](https://ardupilot.org/copter/docs/common-compass-calibration-in-mission-planner.html).
3. **Level horizon** — the level-cal button in Accel Calibration, board mounted in
   its flight attitude.

---

## 8. Props-OFF pre-flight checks

1. **ESC / motor config** — with `SERVO_BLH_AUTO=1` you can open *Setup → Optional
   Hardware → BLHeli ESC* to talk to the Tekko32. Source:
   [DShot ESCs](https://ardupilot.org/copter/docs/common-dshot-escs.html).
2. **Motor order + direction** — *Setup → Optional Hardware → Motor Test.* Confirm
   motors A/B/C/D spin in the ArduPilot order and the correct directions (Betaflight
   numbering differs — do not assume). Fix order by reassigning `SERVOn_FUNCTION` or
   re-plugging; fix a wrong direction via BLHeli or `SERVO_BLH_RVMASK`. Source:
   [Motor order / connect ESCs and motors](https://ardupilot.org/copter/docs/connect-escs-and-motors.html).
3. **Kill switch** — flip the channel-6 switch and confirm *Motor Emergency Stop*
   engages (motors will not spin). Source:
   [Motor Emergency Stop](https://ardupilot.org/copter/docs/channel-7-and-8-options.html).
4. **Arming** — confirm all pre-arm checks pass (they are ON). Fix the flagged
   cause; never disable a check to arm. Source:
   [Pre-arm safety checks](https://ardupilot.org/copter/docs/prearm_safety_check.html).

---

## 9. Generate + load the tripod mission

Generate the AUTO `.waypoints` file for the pass matrix
(`docs/tripod_test_protocol.md` §4). Set `--home-lat/--home-lon` to the **surveyed
tripod GPS** and `--bearing-deg` to the compass direction the **camera faces**:

```bash
# both aspects, boresight + ±5 m offset approaches, 9 m/s full passes:
python3 gen_tripod_mission.py \
    --home-lat 37.8199 --home-lon -122.4786 --home-alt 12 \
    --bearing-deg 90 --alt 10 --speed 9 --slow-speed 3 \
    --lateral-offset=-5,0,5 --passes approach,crossing \
    --out tripod_mission.waypoints
```

Useful flags (`--help` for all): `--leg-length` (far station, default **20 m**),
`--near-range` (near station, **4 m**), `--standoff` (crossing standoff,
**5.5 m**), `--cross-halfwidth` (20 m), `--placard-index-deg` (the mount index
for this block — checked against the HARD ≤4 m/s nose-on cap),
`--off-protocol`. **Negative offsets need the `=` form**
(`--lateral-offset=-5,0,5`) or argparse reads the `-` as a flag.

> ⛔ **DEFAULTS SWEPT 2026-07-25 — they used to manufacture a FALSE NO-GO.** This
> generator shipped `30 / 8 / 17 m`, the geometry `docs/tripod_test_protocol.md`
> §4.1 **superseded on 2026-07-24**: the whole 8–30 m ladder sits *outside* the
> 7.10 m predicted `R_decode90`, so curve (a) would read all-zero and the money
> gate would return **FAIL → do not buy the ~$740 interceptor** for a purely
> geometric reason. Defaults are now the corrected contiguous **4–20 m** grid
> with a **5–6 m tag-envelope crossing standoff**, and the tool now **REFUSES
> (exit 2)** to emit a mission that cannot answer curve (a).
> The one legitimate exception — the curve-(b)/NN crossing block at a 15–20 m
> standoff, which is not envelope-limited the same way — needs `--off-protocol`:
>
> ```bash
> python3 gen_tripod_mission.py --home-lat .. --home-lon .. \
>     --passes crossing --standoff 17 --off-protocol --out nn_crossing.waypoints
> ```
>
> `--self-test` now asserts the **emitted** waypoints against the protocol's
> stations (it previously checked structure + round-trip only, which is why the
> stale defaults passed green for weeks).

The emitted file is **QGC WPL 110** (tab-separated: TAKEOFF → per-pass
`DO_CHANGE_SPEED` + waypoints → RTL). Load it in **Mission Planner** (*Plan → Load
WP File*) or **QGC** (*Plan → Open*). Source:
[Planning a mission with waypoints](https://ardupilot.org/copter/docs/common-planning-a-mission-with-waypoints-and-events.html)
· format: [MAVLink file formats — QGC WPL 110](https://mavlink.io/en/file_formats/).

> The mission encodes range stations as GPS positions relative to the tripod, so
> every pass repeats the same geometry (protocol §4.1). Re-run per field with the
> real tripod coordinates — do **not** reuse a placeholder home.

---

## 10. Fly order (protocol-driven)

1. **Maiden as a plain quad** — Stabilize/AltHold hover, confirm clean flight,
   verify T/W, land. (Do not fly AUTO on an untuned airframe.)
2. **AUTOTUNE** — one AUTOTUNE flight to set the PIDs (`target.param` ships firmware
   defaults on purpose). Source:
   [AutoTune](https://ardupilot.org/copter/docs/autotune.html).
3. **AUTO passes** — Loiter takeoff → confirm fix → switch to **Auto** to fly the
   loaded mission. Log the pass in the protocol §11 session sheet (pass #, aspect,
   speed, tilt, battery).

> ⚠️ **WHERE YOU ARM MATTERS — the fence and the mission have different centres.**
> ArduPilot sets **HOME at the arming point** (row 0 of the mission file is
> ignored on upload), so the `FENCE_RADIUS` tin-can is centred on **where you
> armed** while every waypoint is placed relative to the **surveyed tripod**. Arm
> too far out and `FENCE_ACTION=1` will **RTL the target mid-pass** — which under
> OPTION A's continue-in-AUTO reasoning looks exactly like an RC failsafe and is
> not one. Nothing pre-arm-checks the mission against the fence; with
> `FS_GCS_ENABLE=0` there is no on-site message either, so an unexplained
> mid-pass RTL means *pull the `.BIN` and look for the FENCE/ERR record*.
>
> `gen_tripod_mission.py` **prints the budget for the geometry it just emitted**
> — e.g. `farthest waypoint 20.7 m from the TRIPOD -> … ARM WITHIN 59.3 m OF THE
> TRIPOD` (the off-protocol NN block at `--standoff 17` reaches 26.2 m, so the
> budget drops to 53.8 m). Use that printed number, not one memorised from here.
>
> Same root cause, second consequence: `--alt` is **AGL above the arming point**
> (`MAV_FRAME_GLOBAL_RELATIVE_ALT`), not above the tripod. Arm on ground level
> with the tripod base or protocol §3.1's co-altitude framing is off by the
> ground-height difference. **RTL returns to the arming point**, not the tripod.

---

## 11. After each flight — pull the log

Power off, pull the microSD, copy the newest `.BIN` (one per flight thanks to
`LOG_FILE_DSRMROT=1`). This is the target track for scoring:

```bash
# curve-(a)/(b) + CPA scoring consume the DataFlash POS/GPS track:
python3 scripts/field_score.py --bin-b path/to/target_flight.BIN ...
```

Source: `scripts/field_score.py` (DataFlash `.BIN` via pymavlink DFReader; prefers
`POS`, falls back to `GPS`). Archive the `.BIN` with the session per protocol §12.

---

## Self-test (offline, no hardware)

```bash
configs/target_kakute/selftest.sh        # runs both checks, exits 0/1
# or individually:
python3 configs/target_kakute/gen_tripod_mission.py --self-test
python3 configs/target_kakute/lint_param.py configs/target_kakute/target.param
```

`selftest.sh` passes only if the mission generator's structural + round-trip +
geometry checks pass **and** `target.param` parses cleanly (valid `NAME,VALUE`
lines, no duplicate params, all task-mandated params present + sane).

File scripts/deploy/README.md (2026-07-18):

# scripts/deploy/qemu_arm_check.sh — Pi 5 compute de-risk

**Question this answers:** before spending $120+ on a Raspberry Pi 5, does the
seeker software stack (onnxruntime, the `flight/` guidance core, the camera
ingestion path) even *run* on its CPU architecture (aarch64 / arm64)?

**Question this does NOT answer:** how fast. See the loud disclaimer below —
read it before citing this check anywhere.

## Files

- `qemu_arm_check.sh` — the runnable entry point. Detects an aarch64
  emulation backend (currently: Docker with `--platform linux/arm64`, which
  is QEMU user-mode emulation under `binfmt_misc`), runs the check inside it,
  and prints a runbook if nothing usable is installed.
- `arm_stack_check.py` — the actual payload. Pure Python, no argparse
  surprises; runs standalone too (`python3 arm_stack_check.py --help`).

## What it checks (3 stages)

1. **`flight/` core imports and its math is self-consistent** — the
   pure-Python guidance/geometry/estimator/camera modules that have zero
   hardware dependencies. A few cheap identity checks (not a full pytest
   run — `flight/tests/` already owns correctness on x86_64; this only asks
   "same CPU, same answer").
2. **onnxruntime loads `drone_finetuned_quad_v2.onnx` and runs one
   inference** through `scripts/seeker/v3_onnx_infer.py`'s decode path,
   which the codebase documents as byte-identical to the deployed detector
   (`finetuned_seeker.FinetunedNNSeeker`).
3. **`scripts/frame_source.OpenCVFrameSource` opens and decodes a frame** —
   the generic V4L2/USB/GStreamer camera-ingestion path (works via `cv2`
   alone), pointed at a real captured PNG standing in for a live device.

## Why "non-Picamera path" specifically

This project's `frame_source.py` has exactly one hardware-facing class,
`OpenCVFrameSource`, built on `cv2.VideoCapture`. It is deliberately generic:
a USB/UVC webcam, or a CSI camera exposed through V4L2/libcamera, both work
through the same `cv2.VideoCapture(device)` call. That's what stage 3 dry-runs.

It is **not** the Pi-specific `picamera2`/libcamera Python bindings (this
codebase doesn't use them, and doesn't need to — the Arducam cameras on the
BOM expose a V4L2 device node). Those bindings talk to the real Broadcom/RP1
ISP driver stack and can't be meaningfully exercised under CPU emulation
regardless — there's no real camera silicon to emulate. So "non-Picamera
path" isn't a limitation of this check, it's the actual shape of this
codebase's camera interface.

## What this DOES NOT prove — read this before citing the result

- **Not an fps measurement.** QEMU user-mode emulation interprets/JITs
  aarch64 instructions on the host x86_64 CPU. It is not a speed proxy for
  the Pi 5's Cortex-A76 in either direction — could be much slower, could
  (less likely) look deceptively okay on a fast host. `arm_stack_check.py`
  prints inference timing out of curiosity; it is explicitly labeled
  "NOT an fps proxy" in its own output and must not be used to size the
  seeker loop rate.
  - Real fps needs the **physical Pi 5** (AprilTag path, CPU-only, target
    ~30 fps per `docs/hardware_order_list.md` §0c/§C) or the **Hailo AI
    HAT+ vendor bench** (markerless YOLO path — CPU YOLO is ~5-10 fps and
    explicitly NOT viable at terminal LOS rates per the same doc).
- **Not the real camera driver.** `picamera2`/libcamera + the kernel ISP
  driver need physical hardware. Out of scope by construction.
- **Not MAVSDK/PX4 offboard on ARM.** Not imported by this check. MAVSDK
  ships aarch64 wheels, but the actual offboard link needs a flight
  controller to talk to — a post-purchase integration test, not a
  pre-purchase compute check.

## Status in this environment (as of the last run here)

Neither Docker nor `qemu-user-static`/`binfmt-support` is installed on this
machine, and there is no `/proc/sys/fs/binfmt_misc` aarch64 entry — so
`qemu_arm_check.sh` cannot currently do a real ARM run here. Running it
prints the exact install commands (`--backend auto`, the default) and exits
`2`. See the script's own `print_runbook()` output, or run
`scripts/deploy/qemu_arm_check.sh --help`.

The check logic itself **was** self-tested sim-free on the host
(`--backend host-selftest`, x86_64) using the real ONNX weights and a real
captured frame from `scripts/seeker/data/flight_capture/images/` — all 3
stages pass. That only proves the check script's own logic is correct and
that the stack works on x86_64; it explicitly reports
`"validated_arm": false` and the script refuses to word it any other way.
A sample result: `logs/deploy_checks/qemu_arm_check_20260718T034420Z.json`.

## How to actually get the ARM answer

```bash
# 1. one-time setup (needs sudo; ask first if you haven't already):
sudo apt-get update && sudo apt-get install -y docker.io
sudo usermod -aG docker "$USER"        # re-login after this
docker run --privileged --rm tonistiigi/binfmt --install arm64

# 2. sanity check binfmt is really emulating (not silently no-op'ing):
docker run --rm --platform linux/arm64 python:3.12-slim-bookworm uname -m
# must print: aarch64

# 3. run the real check:
scripts/deploy/qemu_arm_check.sh
```

A Docker-less fallback (raw `qemu-aarch64-static` + a debootstrapped Debian
aarch64 chroot) is documented in full inside `qemu_arm_check.sh`'s runbook
output (`--help`) — heavier and needs root + a few hundred MB download, only
worth it on a machine where Docker itself is off the table.

## Usage

```bash
scripts/deploy/qemu_arm_check.sh                       # auto-detect backend
scripts/deploy/qemu_arm_check.sh --backend docker       # force docker, fail loudly if unusable
scripts/deploy/qemu_arm_check.sh --backend host-selftest  # x86_64 self-test only, NOT an ARM answer
scripts/deploy/qemu_arm_check.sh --model path/to/other.onnx --image path/to/frame.png
```

Results are written to `logs/deploy_checks/qemu_arm_check_<UTC timestamp>.json`
(gitignored, like the rest of `logs/`).

## Expectation, not a guarantee

onnxruntime, numpy, and opencv-python-headless all ship official aarch64
manylinux wheels on PyPI, and `flight/` is pure Python — there's no obvious
reason any of this should fail to *run* on a Pi 5. But that's an
expectation from reading package metadata, not a measurement. Don't skip the
Docker setup and just assume — the whole point of this script is to turn
"should work" into "ran, here's the log."

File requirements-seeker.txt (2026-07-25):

# SEEKER VENV (.venv-seeker) -- the ONNX lane.
#
#   python3 -m venv .venv-seeker            # NO --system-site-packages needed
#   .venv-seeker/bin/pip install -r requirements-seeker.txt
#
# What needs it:
#   * scripts/run_tests.sh stage 2 -- the real-detector ONNX parity tests. Under
#     .venv they `pytest.importorskip("onnxruntime")` and SKIP; routed here they
#     RUN (that is the whole reason two venvs exist -- see run_tests.sh's header).
#   * flight/deploy/seeker_loop.py -- the deployed Pi-5 terminal loop, run as
#     `.venv-seeker/bin/python -m flight.deploy.seeker_loop ...`.
#
# NOT sufficient on its own to reproduce stage 2's numbers: those tests also need
# the detector weights and cached eval frames under scripts/seeker/, which are
# gitignored (docs/license_notice_weights.md). This file pins the CODE deps only.
#
# Pinned to `.venv-seeker/bin/pip freeze --local`, verified 2026-07-25.
# Recorded 2026-07-25 (audit: "dependency rot") -- before that the environment
# these numbers were produced in existed only on this disk.
mavsdk==3.15.3
numpy==2.5.1
onnxruntime==1.27.0
opencv-contrib-python==5.0.0.93   # legacy trackers (detect-then-track, ADR-0058)
opencv-python-headless==5.0.0.93
pupil-apriltags==1.0.4.post11
pytest==9.1.1

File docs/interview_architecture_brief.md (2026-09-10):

# Interview brief — the software architecture, and what did and didn't work

> **Audience:** the builder, in an interview, on a phone. Everything here traces to
> a source in this repo. **Nothing new is claimed** — this is a reading of
> `docs/project_state.json` (the contract), `docs/decisions.md` (97 ADRs), the audit
> and review docs, `README.md`, and the code itself, arranged for a conversation
> rather than for a reader working front to back.
>
> **Rule this doc obeys:** every number carries where it came from and what tier of
> evidence it is (`sim` / `bench` / `derivation` / `retracted`). If an interviewer
> asks "how do you know that", the answer is in the same line as the claim.
>
> **Readable version (phone-friendly, hosted):**
> https://claude.ai/code/artifact/7970c857-927d-4f8f-839f-cd16529a9ce2
>
> Written 2026-09-09. Canonical state always wins: if this doc and
> `project_state.json` disagree, **the contract is right and this file is stale.**
>
> This is a DERIVED view, like `docs/results_notes.md` — it is not part of the
> contract and nothing depends on it. Delete it if it stops paying for itself.

---

## 1. The 60-second version

A counter-UAS interceptor: a quadcopter that flies a pre-programmed open-loop sprint
at a crossing target, then hands off to its **own camera** for the final homing — no
datalink, because the whole point is that the link is the thing an adversary jams.

Two halves:

- **The simulation** — PX4 SITL + Gazebo Harmonic, headless. About 109,000 lines of
  Python and 12,200 of shell; 813 test functions in 57 files (the runner reported 941
  passing tests at the most recent commit that ran it — parametrisation expands the
  count); ten pipeline stages; 97 architecture decision records; Monte-Carlo batches
  on paired seeds. This is the evidence machine.
- **The real build** — Raspberry Pi 5 seeker, Pixhawk 6C Mini, an ArduPilot target
  aircraft. In progress: the target's flight controller is flashed with all 44
  settings verified by reading them back off the board, the camera is measured on
  hardware, and the airframe order is gated on one field afternoon.

**The headline, stated the way the project itself states it:** the guidance law works
and is measured. The camera has **not** beaten a well-aimed blind sprint in any test
flown. Sub-metre interception is real at 10 mph — 8 of 8 flights, median 0.73 m — but
it is *ballistic*, camera off. That gap is the interesting part of the story, and
leading with it is what makes everything else credible.

---

## 2. Architecture: the data path, one hop at a time

The flight is a state machine — `STANDBY → CODED_DASH → ENGAGE → BREAKOFF → SAFE`,
absorbing at `SAFE` (`flight/deploy/real_flight.py`, ADR-0081). Every transition is
guarded and logged, and a setpoint goes out on **every tick in every state**, because
PX4 drops OFFBOARD on a stream gap of about half a second.

Inside `ENGAGE`, this loop runs to contact:

| Hop | What it does | Where it lives |
|---|---|---|
| **DETECT** | Markerless YOLO on **every** frame at 640 px, confidence gate 0.25. No learned tracker. | `scripts/seeker/finetuned_seeker.py` |
| **MEASURE** | Box centre → undistorted bearing; `range = fx · span / box_width_px`. | `flight/camera.py`, `seeker_loop.measurement_from_box` |
| **DEROTATE** | Camera optical → body FRD → NED with the full attitude quaternion; `λ = atan2(east, north)`. Then a camera-to-CG lever-arm correction. | `flight/geometry.py` |
| **ESTIMATE** | Two scalar alpha-beta filters (angle, range): predict every tick at 20 Hz, correct only on a fresh detection (~14 Hz), coast through dropouts. | `flight/estimator.py` |
| **GUIDE** | Pro-nav: `a = N · Vc · λ̇`. Pursuit kept in-tree as the A/B baseline. | `flight/guidance.py` |
| **ACT** | Command → NED velocity + **absolute** yaw setpoint → PX4 OFFBOARD via MAVSDK. | `flight/deploy/seeker_loop.py` |

**The design choice worth naming out loud:** the thing that tracks the target across
frames is **physics, not a second neural network** — an alpha-beta filter plus
proportional navigation. A learned tracker was built, adopted, and later removed (§5.4).

### 2.1 Constants, so they can be quoted

| Quantity | Value | Note |
|---|---|---|
| Pro-nav gain N | **5.0** deployed / FPV; **4.0** in the non-FPV sim default | lab trade study, ADR-0011 |
| Alpha-beta gains | α = 0.5 both channels; β = 0.30 angle, 0.45 range (FPV) / 0.15 (default) | ADR-0009 + addendum |
| LOS rate cap | 60 °/s on the angle channel; **none on range** (parity with the sim harness) | the hazard three latch guards cover |
| Closing-speed floor | 4.5 m/s deployed, 1.5 m/s non-FPV | the range-rate estimate starts near zero from hover, so the lead would build too weakly |
| Control rate | 20 Hz; camera pinned 60 fps; detector ~14 Hz | staleness bounds 0.25 s, well under PX4's 1.0 s offboard-loss timeout |
| Terminal freeze range | 3.5 m | λ̇ is singular as R → 0 |
| Handoff | **5 consecutive** fresh in-window detections | no new detector result **holds** the streak, since 20 Hz outpaces 14 Hz |

### 2.2 Two conventions worth defending cold

**Coordinate frames.** Camera is OpenCV optical (z forward, x right, y down). Body is
FRD. World is ENU for scoring and NED for setpoints. Headings are compass-style,
`degrees(atan2(east, north))` with 0 = north. A positive bearing means the target is
right of boresight — a load-bearing sign, documented at the seeker's definition.

**Why the derotation chain exists** (ADR-0062, FIX-A). The terminal azimuth was
originally `λ = ψ + β`, vehicle yaw plus the target's horizontal bearing in the camera.
That is correct only when the boresight is level. At the measured 27–36° sprint pitch it
inflates the azimuth by roughly `1/cos(pitch)` — a 12–24% gain error straight into the
guidance input — and under roll it mixes the target's *vertical* off-boresight component
into the azimuth.

The fix rotates the full 3-D camera ray with the attitude quaternion, and carries an
**identity guarantee**: with a pure-yaw quaternion the chain reduces to `ψ + β` exactly,
so every previously validated level-flight result is preserved bit-for-bit and only tilt
introduces a change. A 245-case identity grid pins it to under 1e-9.

Measured effect, paired n=8: median miss 2.172 → 1.897 m, tighter on 7 of 8 seeds and
worse on 0, sign test p ≈ 0.035 (`sim`).

**A second, quieter geometry fix in the same family:** pro-nav commands the vehicle about
its centre of gravity, but the camera measures from the camera, 0.1–0.4 m ahead. The
lever-arm correction rotates the body-frame mount offset into NED, adds it to the ray
endpoint, and re-solves range and bearing. Zero offset returns the inputs unchanged.

### 2.3 The portability split, and how it is enforced

`flight/` is the portable core: 22 files, 9,303 lines, pure Python and `math` in the
math modules, with **no simulator imports, no ground-truth imports, no cue imports**. It
runs unchanged on the real Pi and Pixhawk. The sim harness (`scripts/m4_intercept.py`,
5,482 lines) is the throwaway half.

That separation is not a convention, it is a test — three mechanisms:

1. **An AST import-and-identifier closure audit.** `real_flight.py --audit` walks nine
   vehicle modules and flags any identifier starting with a forbidden prefix, any import
   from a forbidden root, and requires **exactly one** call site that sets the sprint
   heading. Exits 0/1.
2. **Mutation calibration.** Tests copy a module, inject each leak shape, and assert the
   audit returns 1. The audit is proven to *fire*, not just to pass.
3. **A sim-side twin.** `tests/test_honesty_static.py` pins the sim engage loop: a loud
   allowlist for the only two legal ground-truth read sites (the log, and the running
   minimum miss), plus a chain-variable check forbidding a ground-truth right-hand side
   on any of the nine variables that reach the command.

**And the honest limit, stated in the code rather than oversold:** this is a
*naming-convention* check, not an information-flow proof. It cannot see ground truth
handed in by a caller under a clean name. The `ground_truth` prefix had to be added after
a planted read slipped past a `gt_`-only guard, because the repo's real accessors are
named `ground_truth_world_points` and `ground_truth_rel_optical`.

Three constants are deliberately **duplicated** rather than imported across the boundary
(exposure spec, calibration minimum, forbidden-prefix list) and pinned equal by contract
tests, because `flight/` must not import dev tooling that will not exist on the aircraft.

### 2.4 Failsafes, and the one asymmetry that is the whole point

Eight failsafes. The interesting design is that the **radio link and the control link are
monitored in opposite directions**:

- The **RF link** is monitored in `STANDBY` **only**. Post-GO link loss is deliberately
  ignored. That *is* the jam-resistance claim — a failsafe that aborted on it would
  delete the headline capability.
- The **OFFBOARD control path** is monitored **only after** GO, with two arms: mode
  not-OFFBOARD persisting past 0.5 s, and a sample older than 3.0 s or negative, which
  catches a dead subscriber that would make the first arm unreachable.

Other details an interviewer would probe: the GO bit is edge-triggered, hysteretic, and
**refuses a switch already high at boot**; a heading latch raises on a second write; and
the distance failsafe prefers the *measured* ground speed and labels its output
`MODELLED` when it has to fall back — because the acceleration constant it would
otherwise use was measured over-predicting travel about 2.7× in the closest-approach
window.

---

## 3. The honesty boundary — the project's actual spine

If there is one thing to lead with, it is this, because it is the part most portfolio
projects do not have.

**The rule.** Ground-truth topics (`gt_*`) are for scoring and logging only. Guidance
sees camera pixels plus the vehicle's own-state EKF, nothing else. Every new guidance
path re-earns a numeric no-cheat audit confirming commands track the *measured* range
where measured and true diverge.

**The loophole, and who found it** (ledger entry `launch-aim-derived-from-ground-truth`).
The rule above polices *when* a value is read. So "the launch aim is solved from the
target's exactly-known track" passed as clean for months — it is a pre-flight constant,
therefore not a live read. That was load-bearing, because aim turns out to be the
dominant lever, and a zero-error cue quietly reduces the demonstration to a ballistic
solution of a known trajectory. The builder caught it by asking, after audits had missed
it.

**The corrected test:** not *when* the value is read but **whether a real system could
obtain it at that quality**. An external cue is architecturally fine — the concept is
cheap interceptors cued by smarter sensors. A cue with *zero* error is not, because no
real cue has zero error.

So every input the system is **given** rather than **measures** now carries a graded
register entry, and a number computed on a `given-perfect` input is reported as a
**best-case upper bound**, never as the claim.

| Assumption register, today | Count |
|---|---|
| Registered assumptions | 20 |
| Actually measured | 1 |
| Supplied error-free (upper-bound inputs) | 4 |
| Currently marked violated | 5 |
| Planned, not yet tested | 8 |

The four error-free inputs: the launch cue, a windless world, a wind-immune target, and
an unmeasured drag table. The five violated include "the camera terminal earns its
handoff" and "the scorer measures the criterion".

---

## 4. What worked

### 4.1 Pro-nav beats pursuit, camera-only — `sim`
Pro-nav 0.402 / 0.277 / 0.443 m against pursuit 2.544 / 2.109 / 2.048 m on identical
target paths — **4.6 to 7.6× better** — on a 2 m/s crosser with the camera as the only
target sensor (M4 gate, ADR-0009, committed logs).

The engineering underneath the number is what to talk about:

- **Raw bearing rate is structurally near-zero** when the yaw loop is actively nulling
  bearing. The LOS rate must be reconstructed in a yaw-compensated inertial frame — the
  standard strapdown-seeker correction. Three independent reviewers flagged this
  unanimously *before* any code was written.
- **Fair by construction.** Both laws share the same actuation and the same yaw,
  altitude and closing loops. The lateral term is the only independent variable.
- **Crossing geometry, not head-on.** Head-on is undiagnostic: with no LOS rotation the
  two laws are indistinguishable.
- **A bench mode that tests the sign convention** before any run is trusted — spin in
  place against a static target and confirm the rate stays near zero. Measured mean
  1.24 °/s under a ±20 °/s spin.
- **Asymmetric gate criteria, by design.** Pro-nav had to be clean *and* under 1.0 m;
  pursuit only had to genuinely fly the same engagement. Requiring pursuit to be "clean"
  would have contradicted the experiment — its failure to close *is* the result.
- **Disclosure rather than selection.** Three earlier dev-phase pro-nav flights that
  same night read 1.04–1.12 m, over the gate, before the final configuration. That is
  stated in the ADR and in `docs/results_notes.md` rather than omitted.

### 4.2 The diagnosis that reordered the project — `sim`
Sixty of sixty fast-crosser flights ended "lost detection at closest approach", miss
about 1.4 m. The intuitive reading is a perception problem. Per-tick forensics over 41
flights says otherwise:

- Miss tracks **zero-effort miss at handoff** with **r² = 0.957** (n=41, 6 m/s). It
  *sharpens with speed*: 0.818 at 3 m/s, 0.957 at 6, 0.994 at 9 — as it should, because
  the fit loosens as terminal correction capacity approaches the delivered miss.
- The bound that does not depend on the simulator: correction capacity is `½·a·t_go²` =
  `½ · 8.7 m/s² · (0.41 s)²` = **0.72 m**, against **1.69 m** already delivered at
  handoff.
- The decisive disproof: the worst flights held the camera locked to short range and
  **still** missed — one by 3.37 m with detections down to 3.47 m. A *perfect* terminal
  camera, point-mass over 150 seeds, removes 100% of the dropout and cuts the miss only
  **25%** (1.003 → 0.755 m).
- The last real detection lands 0.074 s before closest approach at 1.69 m range; the
  blind-window contribution to the miss is **−0.03 m**, i.e. nothing. Field-of-view
  escape is real (LOS rate 485 °/s mean, peaks to 1870, against achieved yaw ≤ 124 °/s)
  but happens 0.037 s before closest approach, as a *consequence* of a miss already
  committed.

Root-cause split of the 1.4 m: ~70% kinematic, ~20–25% recoverable mechanisation loss,
~2% field-of-view escape, ~0% blur, scale or cadence.

**Why it is a good story:** it inverts the intuitive answer with evidence, produces a
bound independent of the simulator, and reprioritised everything downstream. Capacity
scales with time-to-go squared, so acquiring at 12 m instead of 6.5 m raises capacity
from 0.72 m to about 4.3 m. Terminal perception polish went out; acquisition range and
handoff track quality came in.

**And one caveat to state before being asked:** the popular phrasing "96% of the miss is
locked in at handoff" was **wrong and was corrected** — r² is *variance explained*, not
fraction-of-miss; the capacity reading implies about 75% locked in. Two of three
independent audits raised it, and the surfaces were re-worded.

### 4.3 An extended Kalman filter, A/B'd and rejected on evidence — `sim`
The most-asked guidance-and-control interview question, answered with a measured result
instead of an opinion.

A Cartesian constant-velocity EKF was built behind a flag (byte-identical default), then
run in a **pre-registered** paired-seed A/B — n=8, one master seed, identical cue seeds
per run, the estimator as the only difference:

- Primary metric, miss: **null**, exactly as pre-registered. Paired Δ = −0.009 m, 95% CI
  [−0.127, +0.117].
- Secondary, track RMSE: also null. Every paired delta straddles zero (position-track
  n ≈ 780 ticks per arm).
- The finding the headline metric **hid**: alpha-beta clean 8/8, EKF clean 2/8.

**Then the honest part.** The first write-up traced that regression to untuned process
noise. Later forensics showed that was wrong: all six "aborted" EKF flights had
intercepted at normal quality (0.675–1.339 m; three of six *beat* their paired twin), and
the aborts fired about five seconds *after* the pass — the EKF's **physically correct**
post-pass range growth crossed a branch into an abort clock, while alpha-beta's
**physically impossible** negative coasted range, −12 to −21 m, stayed under the
threshold and rode the terminal-hold branch forever. A replay screen found no
over-wide-covariance signature at all. The decision does not flip — alpha-beta stays
default, the nulls stand — but the project **withdrew its own explanation**.

There is also a clean derivation to offer if pushed: alpha-beta *is* the steady-state
Kalman filter for a constant-velocity target at fixed rate and fixed noise, with the gain
frozen and the covariance bookkeeping discarded. So what a real filter buys is exactly
the two frozen assumptions — variable sample interval, and time-varying measurement noise
(camera range noise scales with range). Neither moves a kinematically capped miss.

### 4.4 The measurement discipline
This is what most distinguishes the project, and it exists because failures forced it
into existence.

- **Paired seeds, n ≥ 8, with control arms.** Run-to-run terminal-dropout noise is about
  1 m, so a single-flight delta below that is noise — and claims say "not significant at
  this n" when that is the truth.
- **Pre-registration.** Before any run that could change a belief: the configuration, the
  prediction, the adopt-or-reject criterion, **and what a null would mean**, in writing,
  then it flies. A criterion chosen after seeing the numbers is not a criterion. It has
  been committed *before* the run and cited afterward.
- **Simulation time, never wall time.** Real-time factor sags to 0.3–0.5 under load. This
  cost five development runs and two failed gates: the target mover scheduled its path in
  wall time, so a "2.0 m/s" target moved about 4 m/s in simulation terms and every
  engagement degenerated into a matched-speed tail chase *by construction*. The tell was
  the autopilot's own log showing near-perfect setpoint tracking over 8.8 simulation
  seconds that the telemetry recorded as 18.6 — exactly the ratio.
- **The lab ranks, Gazebo decides.** A design-time surrogate with six documented
  divergences ranks options; only a full-simulator gate turns a ranking into a conclusion.
- **A threshold validated at one operating point is not validated at another.** The
  past-closest-approach breakoff works at 9 m/s, where true range falls about 1 m per
  detection, and silently breaks at 4.5 m/s, where it falls 0.15 m — comparable to the
  noise. Descending the speed ladder would have manufactured a false "slower is worse".
- **Scripted gates.** Eighteen `scripts/check_*.sh`, each exiting 0 or 1. No milestone is
  claimed without running its gate and showing the output.
- **Statistics stated properly.** Wilson and Clopper-Pearson intervals rather than the
  normal approximation, and hit rate computed **per arm, never pooled** across speeds or
  path types, because a pooled curve hides the hard end.

### 4.5 Test architecture, and the "green means ran" rule
The count is not the interesting part. These are:

- **Stage two routes the model-inference parity tests to the one environment that has the
  runtime, and fails if anything skips.** Before that existed those tests skipped
  themselves and had *never* exercised the real inference path — more than a hundred
  tests passed and nothing ran them together.
- **Undeclared skips fail the suite**, each allowed skip named with a human's written
  reason. This found two tests that had been *structurally incapable of running* since
  the day they were written — one called a function that did not exist, one pointed at a
  path that has never existed in any commit — both guarding numbers feeding a ~$740
  purchase decision.
- **Coverage sets are data, not prose.** Every tracked self-test pack must appear in the
  runner, checked against version control. The continuous-integration exclusion list is
  verified by a test that re-collects the whole suite with the simulator bindings blocked
  and asserts the erroring set is *exactly* the declared list — written because a
  hand-maintained list rotted by three files in one day, and an unlisted file is a
  collection error that kills the entire stage rather than skipping one file.
- **Producer-to-consumer contract tests, with the fixture generated from the producer's
  own writer.** A hand-typed fixture is exactly what hid two schema breaks: both scripts
  passed their own self-tests and nothing tested the pair. Eight such seams are covered.
- **Guards against vacuous verdicts**, mutation-verified: an auditor must return VACUOUS
  rather than PASS on zero units, and an anti-mirage comparison must refuse unmatched
  arms.

### 4.6 Hardware bring-up, and one measurement that moved a decision — `bench`
- The Pi 5 runs the fiducial seeker at **96.6 fps** sustained through a 750-second soak,
  57.9 °C maximum, no throttling. The project had *assumed* 30. Root cause was an
  inherited camera-library frame-duration default, not the sensor (143 fps capable) and
  not the processor. Range burned forming the handoff streak scales inversely with frame
  rate, so this cut it about 3.2×.
- Neural inference on the same processor manages **6.09 fps** at 162 ms — inside the
  predicted 5–10 band and **not viable** at terminal LOS rates. So the markerless path
  genuinely requires an accelerator and first real flights fly the fiducial baseline. A
  measurement that closed an argument in the unwelcome direction.
- The deployed camera source measured **60.27 fps on hardware** at its pinned rate,
  exposure **994 µs**, inside the sub-millisecond specification.
- OFFBOARD control verified over a **real serial link with props off** — the one
  connection the simulation never exercised.
- The seeker source now logs what was **applied**, not what was intended, because a
  mutation test that deleted the assignment still saw the old log claim success.

### 4.7 Systems engineering as generated views, not a parallel model
Asked whether to organise the project in Capella, the recognised aerospace tool. The
answer was no, and the reasoning is the interview-worthy part: the state contract **is
already the model** — functional chain, requirements, decisions with rationale, graded
assumptions, verified quantities with provenance, open items. What was missing was not a
model but *views* of one.

So a renderer generates seven views with no hand-authored content, and bakes a SHA-256 of
the contract into the page so the check **fails** if the contract has moved. A
hand-maintained model drifts, and drift is this project's documented failure mode; a
stale systems model shown in an interview is a liability the first time a reader
cross-checks it. Mutation-verified: perturb one field and the check exits 1 naming both
digests.

A companion guard closes the obvious hole: the drift check also requires **every visible
decimal number in the hand-authored dashboard layer to appear verbatim in the contract**,
so numbers cannot drift into the prose a human actually reads.

---

## 5. What didn't work

Longer than the last section, and that is the point. Every item is a committed, dated
retraction rather than a quiet deletion. The through-line: **most retracted results
root-caused to measurement code, not to experiment design.**

### 5.1 The five mirages

| Mirage | What it looked like | Root cause | Corrected |
|---|---|---|---|
| Camera-guided sub-metre intercepts | Sub-metre closest approach credited to the camera terminal | The summariser counted **"any detection during ENGAGE" as camera-guided**. A control arm with **zero** ENGAGE ticks scored 7/7 under 1 m, median 0.54 m — as good or better. Engage began 0.1–1.1 s before closest approach on a *phantom* streak with LOS error ±120–140°; pro-nav on a body-fixed phantom is a no-op | Sprint-only 0.30 m vs with-terminal 0.29 m. The camera added essentially nothing |
| The rebalanced retrain ships | A phantom-free detector winning 16/16 | **A vacuous selection.** Coverage was 0.000–0.019 on all 16 flights and every one aborted "no camera acquire" — so the recorded miss was the *open-loop sprint's* closest approach. The hit-rate headline alone would have shipped a blind seeker | 0/16 acquisitions. Graveyarded |
| Resolution and cropping as the acquisition lever | Recall 47% → 71% from cropping | **The hit test was backwards** — it asked whether the true point fell inside the padded *detected* box, so a 376×368 shadow blob containing a 60×60 target scored a hit | Identical recall at the 8–12 m wall band: 33% vs 33%, and 0% vs 0% |
| The up-tilted camera capture | A physics reading good enough to feed the hardware plan | **The ground-truth labeller was tilt-blind** — the tilt lives in the sensor pose *inside* the camera link and the labeller composed the wrong chain, so every truth box was projected as if the camera were level. That the tilted result replicated the level pattern was the *tell*, not the signal | Invalid, retracted before it reached the hardware plan |
| A static range-and-aspect detection wall | Recall collapsing at range and off-aspect — a sensor limit | The same scoring artifact, plus bins that were 75–87% grounded takeoff ticks and an earlier version that counted post-pass receding ticks as "approach" | The static wall **does not exist**: 100% recall at every range 8–25 m, both aspects, at both confidence thresholds |

A near-sixth, in the same family: frame-top recall 19% and banked-attitude recall 0%,
which happened to *confirm the story the project already believed*. The truth boxes were
labelled at boresight scale with no off-axis widening, against a detector that over-boxes
about 2×, so the size-ratio gate false-rejected exactly the detections being measured.
Re-scoring flipped frame-top **19% → 95%** and banked **0% → 100%**, with the
clean-negative control unchanged at 0/692 — proving the fix did not merely loosen the gate.

### 5.2 The zero-command terminal — the best story in the repo

A single uninitialised variable made the camera arm *brake instead of steer* for whole
engagements, and the honesty auditor was structurally incapable of noticing.

**The mechanism.** Two locals were initialised to zero and, in the coded-sprint branch,
**never assigned** — that branch builds its command directly. The terminal-freeze latch
then captured `(0.0, 0.0)`. Because the markerless detector's monocular range at handoff
reads 1.5–3.5 m while the true range is 10–12 m, the vehicle was *already inside* the
3.5 m freeze radius on the **first** ENGAGE tick, so the block that computes those locals
never ran. Every later tick re-issued a zero horizontal velocity.

**Incidence, measured from the flight logs rather than asserted:** one arm was 7/7 flights
and **661 of 668 ENGAGE ticks (99%)** zero-command; across six arms, **29 of 44 engaged
flights were more than 75% zero-command**.

**Why nothing fired.** The run log literally printed the smoking gun — "velocity vector
frozen at (0.00, 0.00) world" — and no check read it. Worse, the per-tick honesty audit's
only check that tests whether the command follows the camera **discards zero-command ticks
as missing data**. On the broken flights it dropped 88 of 89 usable rows, leaving n=1,
which tripped its own "underpowered" branch — and the flight reported PASS.

> **The line to quote:** the worse the guidance failure, the fewer rows survive the
> filter, the more certainly the check stops gating. *The audit was anti-correlated with
> the defect it existed to catch.*

**Why it manufactured a fake effect.** The defect lives only in the ENGAGE terminal, so it
fired on nearly every camera flight and on **0 of 8** sprint-only flights. The control arm
**structurally could not experience it**. A camera-arm *handicap* therefore read as a
*seeker deficiency*, and the direction of every camera-versus-sprint verdict was
confounded.

**How it was resolved, and this is the honest half.** The fix ported the deployed loop's
law-aware construction so each guidance law latches its own vector, one code path shared
by sim and hardware. A new gating check fails any run that is mostly zero-command. The
verdicts were downgraded to *pending re-fly*, and the 40-flight camera-arm fleet was
re-flown that evening — **reusing the sprint-only twins**, because re-flying them would
have broken the pairing.

The re-fly **confirmed the direction**: zero of 674 pre-closest-approach ENGAGE ticks were
zero-command, and the camera beat its twin on 3/8, 1/8 and 4/8 seeds — never near the
pre-registered 6/8 bar. It also produced one honest **softening**: at correct aim the
camera arm is now roughly at **parity** with the open-loop sprint rather than a slight
liability. And the re-fly surfaced two further blind spots in the auditor itself, both
fixed.

**A residual, tracked rather than hidden:** a second, smaller zero-command path survives —
24 ticks across 5 of 16 flights, worst case five consecutive zero ticks while closing from
7.3 to 4.6 m at 13 m/s. The new check only fails above 50% zero-command, so a 24-tick
burst sails under it. The prescribed fix requires a stricter check **demonstrated to fire
on the old logs** before being trusted on new ones.

### 5.3 The seventh instrument defect was inside the fix for the sixth

A re-score claimed the miss scorer ranged to the camera lens, "verified at **+0.208 m**
above the airframe datum, median over 1,748 ticks", and that correcting it would move the
adopted configuration from **3/16 to 12/16** inside the kill radius — reversing the
project's central negative finding. It was published to the repository front page, the
contract, and the dashboard.

**The defect.** That figure is the median of a *world* z minus a height above the *takeoff
point*. Subtracting one from the other measures the **landing-gear height**. It looked
like a lever arm and had the magnitude of one, so nothing questioned it.

**The true geometry, three independent ways.** The resolved model chain gives +0.002 m. The
physics — lowest collision geometry against the on-pad reading — gives +0.002 m. The
on-pad horizontal readings match the declared offset to four decimal places. Decisive: a
0.242 m mount would make a *parked* vehicle report 0.469 m. It reports 0.229 m.

**The near-miss.** The proposed patch was to return the model origin instead. The model
origin is 0.240 m *below* the airframe datum. It scores 13/16 — a **larger** bias than the
reference it replaced, in the **flattering** direction. A fix for a wrong ruler that would
have installed a worse one, and it would have shipped looking like a correction.

**Why the third pass caught it.** Not "checking harder"; every step had been checked. The
re-scorer *had to state its datum explicitly* to compute anything, and it carries a
pad-height self-check that fails closed — 168 of 168 pass. The lesson: a derived quantity
must carry **what it was measured from**, and a tool forced to name its reference frame
surfaces an error that prose comparing two numbers never will. The tool also reproduces
the *wrong* published table to within 0.0004 m under a mode named `adhoc-published`, which
is how it proved what produced the old figure rather than merely asserting it was wrong.

**Corrected result: 3/16 logged, 5/16 interpolated.** Across 21 arms exactly one
inside-count moves at all. The interpolation fix is real, worth about 0.03–0.06 m, and had
simply been bundled with a vertical drop that does not exist.

**And the retraction *restored* a finding:** re-measured at the corrected centre-to-centre
closest approach over 168 flights, the vertical bias is **median −0.374 m** against
−0.375 m at the camera. It does not move. With horizontal error at 0.174 m, **vertical is
essentially the whole miss** — on a vehicle whose lead solve is explicitly two-dimensional
and whose camera measures target elevation every frame and discards it.

Method integrity worth knowing: yaw is calibrated per flight from on-pad ticks (this world
carries a ~6.2° yaw-datum offset), cross-checked against each flight's own ground-truth
velocity heading; interpolation is closed-form per segment with **no clock in the
computation**, so the wall-time hazard does not apply; 168/168 flights scored, 0 rows
dropped, 0 closest approaches claimed across a logging gap; and the kill radius is
hardcoded **with a test asserting there is no way to tune it**.

### 5.4 Detect-then-track: adopted, then removed
A learned-tracker hybrid — the network acquires once, a classical tracker follows frame to
frame, the network re-validates every eight frames — was the fix for a real problem. At
12 m/s with manoeuvring, the detector threw high-confidence phantom boxes about 18 m off
the true target, and **confidence was inverted**: phantom median 0.34 against real 0.17,
so a confidence threshold is structurally dead. The hybrid recovered post-handoff hit rate
from 3/16 to 14/14 with **zero** phantom handoffs, and the honesty boundary was re-earned
with two independent belts plus a mutation-calibrated static pin.

Then the flat billboard target was replaced with a properly banking 3-D quadcopter, and
**every** tracker tested — the classical one and a learned transformer tracker (0/8) —
*hurt*. With a phantom storm of a median 17 boxes per frame in the 8–12 m band, the
tracker's *seed* is the weak link: a tracker locked onto a phantom is worse than no
tracker, because it is temporally **stable about being wrong**. Network-only on every frame
won the paired A/B, and the adopted configuration today has no tracker.

**Say the lesson out loud:** the tracker was validated against a target shape that
flattered it. A flat board does not bank.
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

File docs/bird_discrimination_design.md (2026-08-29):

# Bird-vs-hostile-UAS discrimination — the SAFETY-CRITICAL design

> **Status:** research + design brief. **A DIRECTION, not yet ratifiable and not yet
> buildable as written** — an adversarial red-team (2026-07) found the architecture
> *direction* sound but the mechanization carrying **structural fail-UNSAFE holes** that
> the doc's own cited numbers expose (terminal-veto timing, confidence-signal semantics,
> streak/track binding). This revision folds in the eight required hardening mitigations;
> the design is safe to **pursue**, not to **ratify/build**, until it is hardened here AND
> the Stage-0 bench sets the thresholds. **Nothing built, nothing run. All operating-point
> thresholds are UNSET, and the interlock DEFAULTS TO VETO-ALL (engage nothing) until the
> bench measures them.** See **§0 Red-team hardening** first. Gated behind the M5 finish
> and the markerless-seeker / EKF-fusion capstone (ADR-0033 item 2, ADR-0034). This is the
> full synthesis of four research lanes (appearance-CV, kinematic + multi-modal, hardware +
> fusion, safety-interlock + sim-test), hardened against the red-team verdict.
>
> **The one question this doc answers:** *before the interceptor commits, how does it
> positively identify that the target is a hostile UAS and NOT a bird — and how does that
> decision survive the comms-denied terminal where the onboard camera is finishing alone?*
>
> **The HARD RULE this doc exists to enforce:** the interceptor MUST positively identify a
> hostile UAS before any commit, and MUST fail SAFE (break off) on doubt. This is both an
> ethics requirement (do not harm wildlife) and the project's own #1 fielded-C-UAS failure
> mode (ADR-0013; ADR-0019 §3: birds are *the* false-alarm source). Every quantitative claim
> below is cited to a paper, dataset, vendor page, or an in-repo ADR/brief — no invented numbers.
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

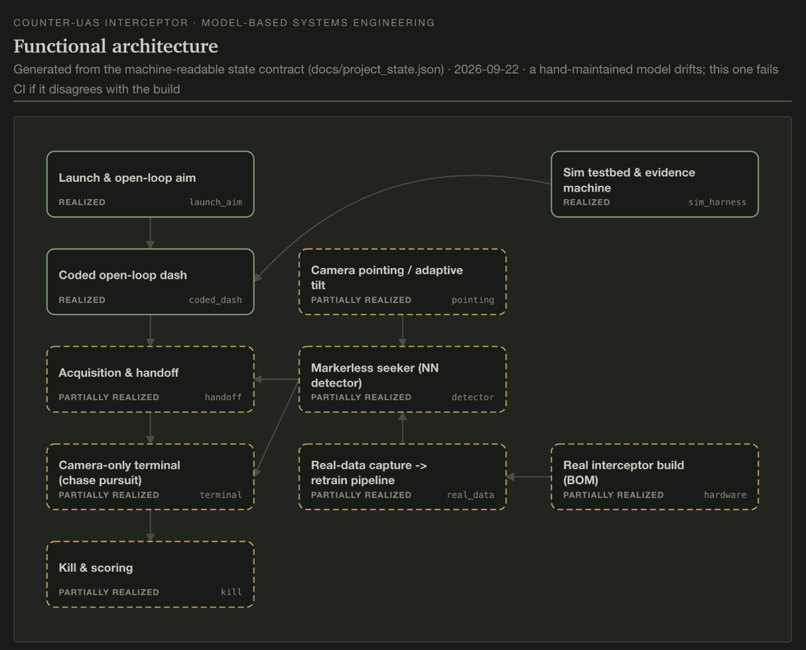
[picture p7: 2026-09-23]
docs/images/linkedin/mbse_functional_architecture.png

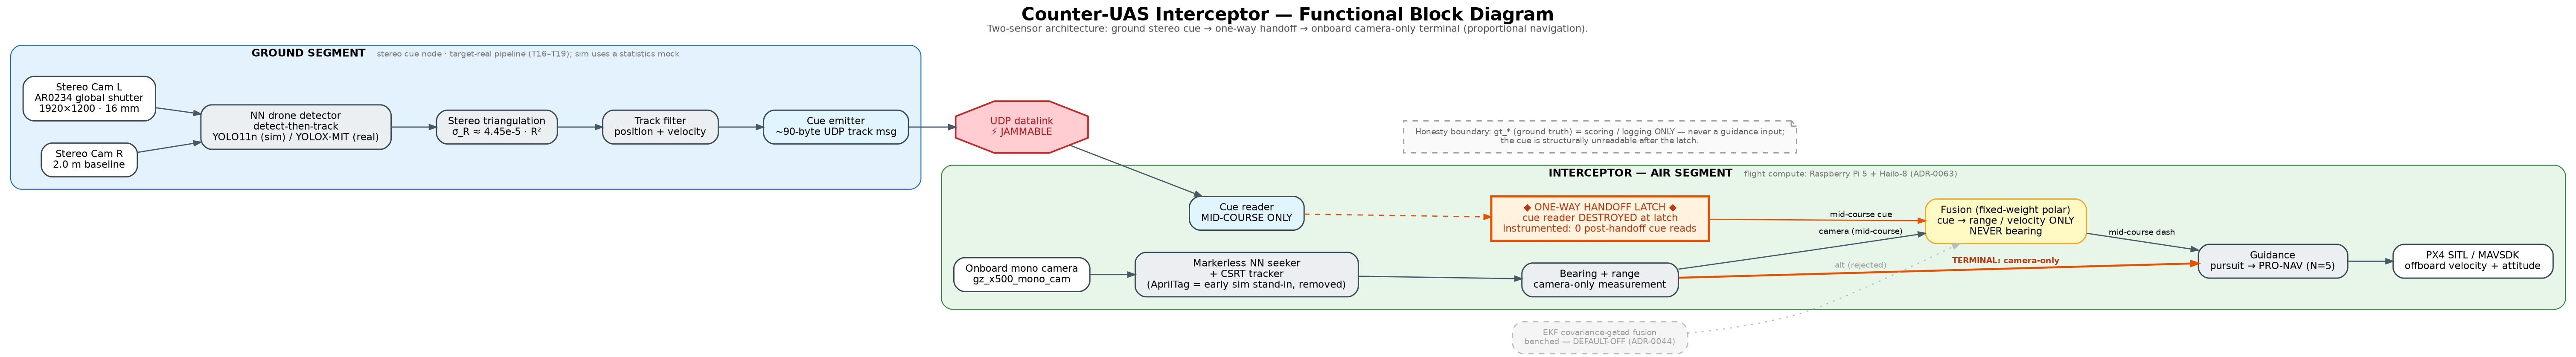
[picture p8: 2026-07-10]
docs/images/architecture_block_diagram.png

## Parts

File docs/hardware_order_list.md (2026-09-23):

<!-- Generated 2026-07-12 by a research workflow (interceptor-hardware-bom). Parent-project hardware BOM for the counter-UAS interceptor + a programmable test target, anchored to the sim-validated design (PX4/MAVSDK offboard, ~100 deg global-shutter cam, up15 tilt [SUPERSEDED — no fixed tilt is sim-validated: ADR-0067 no-adopt + ADR-0068 Stage-1 parity FAIL; adaptive tilt #46/ADR-0065 is the open lever], Pi-class compute, AprilTag target). Prices are estimates — verify at purchase. -->

# Interceptor Hardware — Purchase-Ready Order List

*All prices are ballpark USD, "verify at purchase" (FPV / Pi pricing is moving in 2026). † = **skip if you already own it.** Recommended tier shown in the tables; budget/splurge swaps are in section 2.*

---

## 0. Coded-dash pivot — what the new objective changes (2026-07-15)

This list was drawn up for the older ground-cued design. The objective is now the
**coded open-loop DASH → CAMERA-ONLY terminal** (`docs/real_build_coded_dash.md`,
ADR-0076 add #18, Fable review 2026-07-15): no ground-sensor cue, no datalink
mid-course — a pre-programmed dash, then the onboard camera+NN flies the intercept.
**Most of the BOM is unchanged** (airframe A, autopilot B, compute+camera C, power,
safety F all still needed). The deltas that affect **what to buy**:

- **① Wide FoV is now a HARD REQUIREMENT, not a tunable — do NOT buy/fit a narrow or
  long lens.** The coded-dash acquires a crossing target from a *roughly*-aimed dash;
  that robustness (validated at ±30° aim error, 48/48 flights still acquired) *depends
  on* the ~100° FoV. A narrow lens re-creates the "fast crosser walks out of frame,
  0/12" failure (ADR-0024). The M12 set is fine — fit **only** the ~2.5–2.8 mm (~100°)
  element and keep the rest as spares. (This supersedes the old "narrow-lens-first"
  acquisition-range advice.)
- **② The camera mount must attempt PROP CLEARANCE — the $0 fix for the false-HANDOFF
  hazard (own-prop phantom).** *(was "the #1 seeker failure" — superseded, see the bracket at the
  end of this bullet)* In sim, the interceptor's own prop blades read as a false target
  ("phantom") the camera-only terminal can lock with no cue to veto it. Mounting the
  camera **forward of / above the prop disc** so the blades sit outside the ~100° FoV
  designs the phantom out for free. **Geometry check (audited on the Mark5 Pro):** a
  mid-deck camera CANNOT clear (prop-disc points ~35–40° off-axis, inside ±50°); only a
  **nose-cantilever** mount (flush at the front-plate edge + ~20 mm forward) gets the blades
  outside ~100°, and even then the margin is thin (~11° flush) and real barrel distortion
  captures *wider* than pinhole math — so **design for the forward overhang, BOM a spare
  camera+boom (it's first into the ground on a bad day AND first into the *target* on a good
  one — sacrificial each contact kill), and treat the bench corner-spin check (§3) as a HARD
  gate — run it at LOADED throttle across the FULL adaptive-tilt sweep (0→tilt-max), NOT
  idle+level: up-tilt (the dominant wall-lever, #46) rotates the FoV toward the thin ~11° prop
  margin and blade coning under load pushes tips forward, so the bench-verified clearance angle
  CLAMPS `--adaptive-tilt-max-deg` (Fable gap-check 2026-07-17; contract `forward-camera-boom`).**
  ⚠️ **There is NO software fallback:** the phantom-free retrained seeker was
  measured FAILING in flight (0/16 acquisitions, ADR-0076 add #18d — `quad_v2` stays deployed).
  Clearance-by-geometry + the no-cue handoff hardening are the ONLY mitigations.
  **[SUPERSEDED IN PART 2026-07-16, ADR-0076 add #18g/#18h/#18k: the camera-forward flight removed
  the phantom (approach-phase phantom detections 1187→1) but acquisition was UNCHANGED — the phantom
  is the false-handoff hazard, NOT the #1 seeker failure and NOT the acquisition blocker. The mount
  stays mandatory (all software phantom separators are NULL), but the binding seeker failure is
  in-flight approach recall ≈0 — a pointing/dash-pitch wall whose levers are adaptive camera tilt
  (#46/ADR-0065) + the real-data detector hypothesis. See docs/project_state.json.]**
- **③ Add a checkerboard calibration target** (below) — the wide M12 distorts, and every
  range/bearing is wrong until `scripts/calibrate_camera.py` runs. This is the first
  bench gate; it's ~free to print.
- **④ The Hailo-8L (single NPU stream) is confirmed correct.** The pivot makes the NN
  the *sole* single-stream terminal seeker, so the pricier Hailo-8's second stream is
  not needed — keep the 8L (already the recommended part).
- **⑤ No guidance datalink is needed** (this is the jam-resistance story). The ELRS link
  (B) is **safety/kill + arming only**; the SiK radio (D) is **telemetry monitoring
  only**. Neither carries guidance — the interceptor flies the dash open-loop and the
  camera finishes it. No cue radio, no ground sensor rig, no second (cue) camera.
- **⑥ ⚠️ SUPERSEDED (2026-07-16, ADR-0076 add #18j-fix/#18k; see docs/project_state.json
  graveyard):** foveated auto-crop is NOT an acquisition-range lever (crop = full-frame recall at
  the 8–12 m wall band — the 3rd mirage) and the real-data fine-tune is DEMOTED to an
  outdoor-appearance hypothesis; the wall is flight-dynamic POINTING (~40° nose-down dash pitch) —
  spend the range effort on adaptive camera tilt/pointing (#46/ADR-0065). Still true: do NOT buy a
  lens or higher-res sensor for range (honesty gate unchanged, §2). Original (kept for the record):
  **Acquisition range** ("interceptor distance") is bought in **software first** —
  foveated auto-crop on the AR0234's *native* resolution (we currently downscale
  1280→640 and throw pixels away) + a real-data fine-tune. **No new hardware** buys more
  range here; a higher-res sensor is **honesty-gated** (§2). So the AR0234 as-specced is
  right; spend the range effort on the crop/retrain, not a lens or sensor swap.
- **AprilTag stays the flight BASELINE seeker** (not just a sim stand-in): first real
  intercepts fly on the tag; YOLO is validated in shadow mode alongside it before it
  ever steers. So the target's AprilTag placard (E) is load-bearing, not optional.

---

## 0b. Pre-purchase audit (2026-07-15, Fable-reviewed + web-verified) — fixes applied + open items

Verdict: **good to order after the items below.** The core interceptor stack (A–D) verified sound
(6S closes; two-rail power correct; Pi 5 + AI HAT+ + AR0234 coherent, single NPU stream; mount
patterns consistent; PM02-analog↔6C-Mini right; SiK/Pi UART ports + params correct; AUW/T-W
arithmetic plausible). **Applied inline** (2 blockers + fixes):

- **[SETTLED 2026-07-20 — Matek] Target FC** *(SUPERSEDED same-day at checkout: the "one-purchase alt" WON — the ORDERED cart carries the **Holybro Kakute H7 V1.5 + Tekko32 F4 65A** (§0d ORDERED banner + `bom_tiers`; ArduPilot firmware target `KakuteH7`, configs/target_kakute/). The Matek analysis below is kept for the record — ledger `target-fc-matek-vs-kakute`.)*: the SpeedyBee path is dead — F405 V4 DISCONTINUED, F405 V5 OUT OF STOCK everywhere reachable (only a 3× Amazon markup). Switched to **Matek H743 (SLIM/WLITE) + a 45–55 A 6S 4-in-1 ESC** — the ArduPilot-native brand, long-standing OFFICIAL support (not a fresh merge), broadly stocked (GetFPV/Pyrodrone/RDQ/Amazon). Cheaper if in stock: a current **Matek F405** board + ESC; one-purchase alt: **Holybro Kakute H7 + Tekko32**. ~$138–155 (H743) / ~$80 (F405) — +$35–75 vs the SpeedyBee stack; standalone FC so add the ESC. (E)
- **[BLOCKER→fixed] Interceptor RC path** ELRS **CRSF-to-UART → SBUS-to-RC-IN**: the 6C Mini has
  only 4 UARTs (GPS/SiK/Pi spoken for) and stock PX4 has no CRSF driver; SBUS→RC IN needs neither. (B)
- **[fixed] Compute BEC** Pololu 5.0 V → **Matek BEC12S-PRO 5.2 V** (avoids Pi-5 undervolt throttle). (C)
- **[fixed] Prop-clearance honesty** §0② now states there is NO software phantom fallback (the
  retrained seeker fails in flight, add #18d) → nose-cantilever mount + a hard bench gate.

**MISSING — add to the order:**
| Item | ~Cost | Why / unblocks |
|---|---|---|
| ~~RTK GNSS pair (u-blox ZED-F9P ×2)~~ **CUT** — see §0c | ~~$220–300~~ **$0** | Was "non-negotiable" ONLY to *measure* a <1 m CPA. The builder re-scoped the criterion to a **BINARY KILL** ("takes the drone out or not", 2026-07-15), which is confirmed by **video (seeker recording + phone slow-mo) + both FCs' ULogs**, not sub-meter RTK. Cut it. (Buy later only if you want a citable sub-meter *number* for the portfolio.) |
| **Broadcast Remote ID module ×2** | ~$35–60 ea | **LEGAL:** both aircraft >250 g outdoors (US) need FAA reg + broadcast Remote ID; neither FC provides it. (Alt: a FRIA field.) |
| **Thrust test rig** (DIY inverted on a scale) | ~$20 | §3 demands a bench T/W re-verify (and roadmap R4e: characterize real max lateral-accel — the one variable that can move the kinematic floor); nothing was listed. |
| **Interceptor lost-model buzzer** | ~$5 | The 6C Mini has no onboard buzzer; the (E) buzzer is on the TARGET. The interceptor lands out after BREAKOFF. |
| **M2.5 nylon standoff/screw kit** | ~$8 | Mounts the Pi 5 + AI HAT+ to the printed tray; not in the consumables kit. |
| **IR-cut filter check on the flight M12 element** | ~$0–8 | Bare M12 kit lenses often lack IR-cut → magenta cast outdoors → hurts a color-trained YOLO. Verify or add. |

*Camera-exposure note (roadmap R4d):* the motion-blur bench gate must be run at **TERMINAL LOS rates
(≥300°/s, exposure ≤1 ms)**, not the 60°/s mid-course spec — terminal rates are 485–1870°/s and a
5 ms exposure smears ~23 px. Confirm the AR0234 can hit ≤1 ms exposure outdoors (it's global-shutter,
so it can — but verify the driver exposes the control).

**✅ RESOLVED 2026-09-22 — option (b) chosen by purchase: a 2nd RadioMaster Pocket is ORDERED (§0d Tier-2 banner; ADR-0089/ADR-0109). Remaining setup work: Model Match on both TXs, same ELRS version + bind phrase. Original question kept for the record:** **(was: ⚠️ OPEN DECISION (yours — audit S2): two aircraft, one TX.)** One TX + both RX on the same bind
phrase REQUIRES **Model Match** (else both aircraft answer the same sticks — dangerous). But then the
*unselected* aircraft is in RC failsafe — so while you hold the interceptor's kill, the **target has no
independent RC kill.** Choose: **(a)** target ArduPilot continue-in-AUTO on RC-failsafe + tight geofence
(`FS_OPTIONS`/`FENCE_ACTION`), accept no target kill during runs; or **(b)** add a 2nd cheap TX
(RadioMaster Pocket ~$65) + a 2nd operator. Pick one before ordering.

**Notes:** the (D) 22↔15-pin CSI adapter is **redundant** (the AR0234/B0353 ships a 150 mm 15→22-pin
Pi-5 cable — keep the $6 line as a spare/length option). Order the **TX16S MKII internal-ELRS** variant.
Lens: ~2.5 mm ≈ 98° / ~2.7 mm ≈ 94° on the AR0234 — fit 2.5 mm, calibrate, pick nearest fx≈540@1280.
Pin the flight Pi's kernel (Arducam Pivariety driver is kernel-fragile).

**Net price delta:** ~~roughly **+$250–400** over the prior ~$1,936 (RTK pair dominates; V4/BEC swaps save
a little) — the RTK is what makes the <1 m goal *measurable*, so it's load-bearing, not optional.~~
**[SUPERSEDED 2026-07-15 by the §0c binary-kill re-scope: the RTK is CUT (see the table above + §0c)
and the <1 m measured-CPA goal is re-scoped to a BINARY KILL on video + both ULogs. Remaining §0b adds
(rig/buzzer/standoffs/IR-cut, ~$33–41; Remote ID deferred — $0 at a FRIA field) minus the V4/BEC swap
savings ≈ a small net delta; current totals live in §0c (~$1,390 all-new / ~$740 interceptor). See also
docs/project_state.json.]**

---

## 0c. Binary-kill COST-CUT re-scope (2026-07-15, Fable-reviewed) — the lean build

Builder re-scoped the success criterion to a **BINARY KILL** ("ideally it either takes the drone
out or doesn't") and asked to cut cost while keeping the project possible. That moots the precision
metrology and lets budget-tier parts in (a *ram vehicle* SHOULD use cheap parts — expect to break
some on both aircraft per successful attempt, so have spares before the first attempt).

**NEW TOTALS:** interceptor **~$740** (was ~$1,300+ with 0b); **everything all-new ~$1,390**
(was ~$2,200–2,300); **~$1,080 if you own TX/charger/tools/USB.** **Saved ~$850–900.** Evidence
under binary-kill = the **seeker camera's own recording + phone slow-mo + both ULogs** (target
attitude/altitude collapse, interceptor accel spike) — $0, and keeps a defensible "camera-only
intercept, kill confirmed on video + logs" claim (gives up only a citable sub-meter *number*).

**THE CUTS (ranked by $ saved):**
| Item | From → To | Saved | Note |
|---|---|---|---|
| RTK pair (§0b) | $220–300 → **CUT** | **$220–300** | binary-kill needs no sub-meter measurement (above) |
| RC TX | TX16S $205 → **RadioMaster Pocket** $65 | **$140** | same ELRS/EdgeTX. **Better: 2× Pocket ($130, save $75) — also fixes the §0b S2 two-aircraft-kill hole** (independent target kill) |
| Camera | AR0234 color + M12 set $150 → **Arducam OV9281 mono GS wide** $36 | **$114** | still global-shutter (the real need) + native libcamera (no Pivariety kernel pain); mono fine for AprilTag. **Flags:** verify HFOV ≥100° on calibration; 1 MP = shorter R_acq + no foveated-crop headroom (re-run the M2 range gate) *(the "no foveated-crop headroom" con is VOID — crop retracted as a range lever, ADR-0076 add #18j-fix, which weakens the range-grounds case for the AR0234 upgrade)*; YOLO later needs a mono retrain (folds into the mandated real-data fine-tune). AR0234 = the upgrade path if range measures short. |
| Telemetry | SiK pair $75 → **DEFER** | **$75** now | monitoring-only (§0⑤); bench/first-hovers over USB + Pi-5 WiFi→QGC. Buy before long-range autonomy. |
| **AI HAT+ (Hailo)** | $70 → **DEFER** | **$70** now | first kills use the **AprilTag baseline (30+ FPS on Pi 5 CPU)** — no NPU needed. CPU YOLO (~5–10 FPS) is NOT viable at terminal LOS rates → buy the HAT when you graduate to the *markerless* kill (an upgrade, not the gate). |
| ESC | Tekko32 65A $88 → 45–55A budget 4-in-1 $42 | **$46** | ample for 2207/6S; watch bench temps |
| Motors | XING2 $84 → EMAX ECO II 2207 $56 | **$28** | T/W still ≥5:1; **shares a spare pool with the target** |
| Frame | Mark5 Pro $60 → TBS Source One V5 $33 | **$27** | re-run the §0② nose-cantilever prop-clearance on the new frame (mandatory anyway) |
| Spares (G) / 3rd LiPo | partial → **DEFER** | **$82** now | keep consumables; buy spare arms/motor/RX + 3rd pack *before* kill attempts |

**DON'T cut:** Pi 5 8GB → 4GB saves only ~$10–30 now (2026 DRAM crisis collapsed the gap — buy 8GB from an official reseller, not Amazon scalp prices).

**KEEP — non-negotiable (project dies without these):** Pixhawk 6C Mini + M10 GPS; a **global-shutter
camera at ≥100° FoV** + checkerboard + nose-cantilever prop-clearance mount (no software phantom
fallback, add #18d); Pi 5 8GB + 5.2 V BEC + active cooler; ELRS RC **kill** + the **whole safety
bundle** (smoke stopper, LiPo bag, fire blanket, glasses, cell checker — never cut safety on a
vehicle built to hit things); **both microSD cards** (ULogs + onboard video ARE the metrology now);
the **target drone + AprilTag placard**; the $20 DIY thrust rig + $5 buzzer + $8 standoffs.

**DEFER (buy when the phase needs it):** AI HAT+ $70 (markerless phase) · SiK $40–75 (long-range) ·
3rd battery $26 · spare arms/motor/RX $56 (before kill attempts) · Remote ID $0–180 (**legal, not
metrology — $0 at a FRIA field, else 2 modules; decide by field before outdoor flight; FAA reg $5/
aircraft either way**) · AR0234 upgrade $150 (only if OV9281 range measures short).

> **THE LEAN "camera-only kill on video" BUILD — ~$1,390 all-new / ~$1,080 if-owned:** interceptor
> **$740** + target **$273** + ground/safety **$343** (Pocket TX, charger, safety, solder, tools) +
> consumables **$35**. Kill confirmation $0 (video + ULogs). Phasing unchanged (§4): buy target + TX +
> charger + safety/solder first (~$580), spread the ~$740 interceptor across Phases 1–3.

---

## 0d. STAGED BUY — the order plan (2026-07-17, reconciled with the dashboard `build_plan` + pre-order stress-test)

Order in TWO tiers, gated so you never spend on the wrong thing. **Canonical/always-current: the dashboard's `bom_tiers` + the P0–P5 `build_plan` in `docs/project_state.json` (hosted view: the standing Artifact URL in `artifact_url`).** This section is the order-list mirror.

> **✅ [ORDERED 2026-07-20 — Fable GO-WITH-FIXES]** Cart placed: the **target-drone stack** (Kakute H7 V1.5 + Tekko32 F4 Metal 65A + ECOII 2207×4 + Source One V6 + M10Q + RP1 RX + Pocket M2 TX + CNHL 6S + charger + props), the **seeker kit** (innomaker OV9281 + Pi 5 + Wonrabai 22→15 CSI cable + microSD + reader + PSU), and the **interceptor BRAIN** (Pixhawk 6C Mini + PM02 V3 + Holybro M10 — front-loaded past the money gate; acceptable, ADR-lite deviation logged). **Two fixes before/at checkout:** (1) re-source the **Pi 5 ($175→~$80)** + **SanDisk 128GB ($45→~$20)** from PiShop/CanaKit — recovers ~$120; (2) add the **build/field layer** the cart lacks (solder+safety+XT60, a **microSD for the Kakute** = the target's DataFlash log, 18650s for the TX, +2 LiPo packs, active cooler, tripod, USB-C PD power bank, AprilTag placard, checkerboard, FAA/Remote-ID). Full list + prices in the dashboard `bom_tiers` Tier-1 must-add rows.

**TIER 1 — first steps: NN-validation + compute de-risk (buy FIRST, no result-gate).** Prove the riskiest bets cheaply before any interceptor money. Contents: **target drone (E) + AprilTag placard (E) + OV9281 camera (C) + Pi 5 8GB (C) + checkerboard (C) + USB/power bits (D)**. Hardware ~$475; to actually *fly* the target for the test you also need the ground/safety gear (TX/controller + charger + LiPos + safety/solder, from F) → **~$620–780 realistic first-outdoor-test outlay** if none owned (the ~$310 tripod-test *core* = target + tag + camera). **Do the P0 desk checklist first** (frame-top sweep, placard-sizing, camera paper-checks incl. the vertical-FoV 800-vs-960 check, FAA/Remote-ID). Purpose: the tripod afternoon (build_plan P2) yields TWO curves in one session.

**⛔ THE MONEY GATE (two curves, one test) — this is the money logic, get it right:**
- The **AprilTag decode-envelope** curve GATES the **Tier-2 ~$740 interceptor** — first kills fly the TAG on the Pi 5 CPU (§0c), so the tag must decode the approaching placard early enough for a handoff (t_go ≥ 0.5 s) before you commit the airframe.
- The **markerless-NN approach-recall** curve GATES ONLY the **Hailo HAT + markerless phase** ($70, deferred). A poor NN curve does NOT block the interceptor — it just defers the markerless upgrade.

**TIER 2 — the lean §0c interceptor (~$510 this tier → ~$740 all-in with Tier-1 carry-overs).** Everything the airframe needs that Tier 1 didn't buy (A + B + rest of C + D): frame, motors, ESC, 6C Mini, M10 GPS, ELRS RC (kill/arm only), LiPos, PM02, 5.2 V BEC, props, storage, cables, cooler, and the **prop-clearance + FIXED up-tilt mount** — angle = the real airframe's measured **dash pitch** (build-specific ~25–40°, NOT sim-sized): print an **ADJUSTABLE 10–30° bracket** and lock it from the first dash ULog. ~~Order only after the Tier-1 **tag** curve passes the gate.~~

> **🟧 [ORDERED 2026-09-22 — builder, AHEAD of the money gate (ADR-0109)]** The Tier-2 airframe
> order went in before the tripod tag-decode curve flew — the builder's call, spend-side only
> (the curve still gates KILL-ATTEMPT flights and the Hailo/markerless phase). Placed:
> **TBS Source One V6** frame $41.99 · **Skystars KO60II 60A 3-6S AM32 4-in-1** ESC $36.99
> (upgraded from the 45–55A plan) · **EMAX ECOII 2207 1900KV ×5** ~$149 (4 + the §G spare;
> arrive ~Oct 5–15, the long pole) · **RadioMaster RP3 ELRS diversity RX** $31.99 ·
> **Matek 12S Pro BEC** $24.99 · **Holybro PM02 V3** $24.99 (replacement — first unit
> vendor-refunded) · **2nd RadioMaster Pocket (CC2500/ELRS combo, ELRS 2.4G)** $84.49
> (closes ADR-0089 / the §0b S2 two-aircraft-kill hole → option (b)) · **HQProp V2S 5x4.3x3
> ×16** ~$19 (shared with the target) · **Flywoo Finder V1.0 buzzer ×2** $23.98 (one per
> aircraft, closes the §0b buzzer line) · LiPo bag + zip ties (Amazon).
> **STILL MISSING for a full intercept:** FC High-Endurance microSD (ULogs = metrology; confirm
> the 6C Mini kit), M2.5 nylon standoffs, the $20 thrust rig, the three prints (camera mount /
> checkerboard / placard), the field layer (PD power bank, tripod + head, cones/tape, +2 6S
> packs), and the kill-attempt spares (arms / spare RX). **Bench-verify:** the 12S Pro's 5 V tap
> must deliver Matek's spec'd **5.2 V under Pi load** (the listing rounds to 5 V), and both
> Pocket TXs need **Model Match** + the same ELRS version/bind phrase.

---

## (A) Interceptor airframe & power

| Item | Qty | ~Unit | ~Line | Where | Why + key compatibility |
|---|---|---|---|---|---|
| GEPRC Mark5 Pro 5" freestyle frame | 1 | $60 | $60 | GetFPV / Pyrodrone / RDQ | Roomy squashed-X with a real top deck for the Pi/camera tray. 30.5×30.5 **and** 20×20 mounts, 16×16 M3 motor mount. |
| iFlight XING2 2207 1855KV motor (6S) | 4 | $21 | $84 | iFlight / RDQ / Pyrodrone | ~1.4–1.6 kg/motor → T/W ≈ 6:1 at 950 g AUW. 6S, 16×16 M3, spins 5.1" tri-blade. |
| Holybro Tekko32 F4 Metal 65A 4-in-1 ESC | 1 | $88 | $88 | Holybro / GetFPV | 65A headroom for a loaded agile quad; DShot600. 4–6S, 30.5×30.5 stack, driven from the Pixhawk PWM header. |
| Holybro PM02 V3 power module (**analog**) | 1 | $19 | $19 | Holybro / GetFPV | Feeds 5.2V + V/I telemetry to the FC. **Must be analog PM02 (not digital PM02D)** to match the 6C Mini. XT60 pass-through. |
| HQProp 5.1×4.6×3 tri-blade props (4-pack) | 4 | $4 | $16 | GetFPV / RDQ | 1 flight set + 3 spare sets (you WILL break props). 5.1" tri, M5 T-mount, buy CW+CCW. |
| CNHL Black 6S 1500mAh 100C LiPo (XT60) | 3 | $26 | $78 | ChinaHobbyLine / GetFPV | Sized to the 950 g AUW; 3 packs = a full test day. ~245 g each (the mass in the AUW budget). |
| Battery straps + XT60 pack + 16 AWG wire | 1 | $10 | $10 | GetFPV / Amazon | Secures the LiPo; spare XT60 pigtails + thick wire for the power taps. |

**Subtotal (A): ~$355**

---

## (B) Autopilot, GPS & radio link

| Item | Qty | ~Unit | ~Line | Where | Why + key compatibility |
|---|---|---|---|---|---|
| Holybro Pixhawk 6C Mini (STM32H743, FMUv6C) | 1 | $131 | $131 | Holybro / GetFPV | **The exact stack the sim validated** — native PX4 + OFFBOARD/MAVLink → params & guidance transfer directly. Buy the kit with the cable set. Vibration-mount it (not a stack board). |
| Holybro M10 GPS + IST8310 compass | 1 | $45 | $45 | Holybro / GetFPV | GPS + mag for outdoor position hold + the target's box mission. JST-GH to GPS1; mount on a short mast (compass EMI). |
| RadioMaster RP3 ELRS 2.4GHz diversity nano RX | 1 | $22 | $22 | RadioMaster / RDQ | 2-antenna link holds through hard terminal maneuvers. **Flash it to SBUS output (ELRS ≥3.3.0) and wire to the 6C Mini's dedicated RC IN pin — NOT a UART.** Two verified reasons (Holybro 6C Mini + PX4 docs): the Mini has only 4 UARTs (GPS1=GPS, TELEM1=SiK, TELEM2=Pi → only GPS2 free), and **stock PX4 has no CRSF driver** (CRSF needs a custom firmware build). SBUS → RC IN uses stock PX4, consumes zero UARTs, keeps GPS2 as a spare. Loses CRSF link-stats *in the PX4 logs* only (fine — this link is kill/arm-only, §0⑤). **Must match the ELRS TX (F) — same firmware + bind phrase.** |
| SanDisk High Endurance 64GB microSD (FC logs) | 1 | $12 | $12 | Amazon / Best Buy | PX4 writes ULog flight logs here — your portfolio proof. High-Endurance survives sustained sequential writes. |

**Subtotal (B): ~$210**

---

## (C) Onboard compute, camera & fixed-tilt mount

| Item | Qty | ~Unit | ~Line | Where | Why + key compatibility |
|---|---|---|---|---|---|
| Raspberry Pi 5, 8 GB | 1 | $120 | $120 | PiShop / SparkFun / CanaKit | Runs the whole sim stack natively: MAVSDK-Python + OpenCV + AprilTag on CPU while the NPU does YOLO. 5V/5A USB-C. ~46 g. |
| Raspberry Pi AI HAT+ 13 TOPS (Hailo-8L) | 1 | $70 | $70 | PiShop / SparkFun | YOLO11n @640px at 30+ FPS on the NPU → CPU stays free for MAVLink + guidance. Pi-5-only (single PCIe lane). Stacks over the cooler. |
| Official Pi 5 Active Cooler | 1 | $5 | $5 | Adafruit / PiShop | **Mandatory** under sustained YOLO load — prop wash alone isn't enough. ~25 g. |
| Arducam AR0234 2.3MP **color global-shutter** CSI (B0353) | 1 | $120 | $120 | Arducam / UCTRONICS | Global shutter = **no rolling-shutter smear** (your hard requirement). 2.3MP overspecs the sim's 1.2MP; color aids YOLO + demo. Needs Arducam's Pivariety driver (extra setup). |
| Arducam M12 lens set (10 lenses, 20–180°) | 1 | $30 | $30 | Arducam / Amazon | Fit the ~2.5–2.8mm element for the sim's **~100° HFOV** (stock B0353 lens is only ~90°). **Fit ONLY the wide element — the ~100° FoV is a coded-dash REQUIREMENT (§0①), not a tunable; keep the narrow/long lenses as spares, do NOT fly them.** Wide M12 distorts → **checkerboard calibration mandatory** (`scripts/calibrate_camera.py`; `flight/camera.py` undistorts). |
| 3D-printed up-tilt + **prop-clearance** camera mount (up-tilt 10–30°, detent ~15°; camera fwd/up of the prop disc) | 1 | $0–15 | $0–15 | Self-print, or JLCPCB/Craftcloud print service | ~~Sets the sim's up15 tilt (ADR-0067)~~ **[UPDATED 2026-07-17 — a FIXED up-tilt is now the FINALIZED decision (builder chose fixed over adaptive for simplicity; adaptive REJECTED). Angle = the airframe's steady DASH PITCH, set from the first real dash ULog (build-specific ~25–40°, NOT sim-sized) — so print an ADJUSTABLE 10–30° bracket and LOCK it after that measurement. Prior up15 NULL (ADR-0068) was a cue-era terminal-PARITY test, a different context. See the pointing decision in `docs/project_state.json`.]**. Bracket retained for PROP-CLEARANCE (§0②, still valid — add #18h): pushes the camera **forward/above the prop disc so the blades sit outside the ~100° FoV** — the $0 fix for the own-prop phantom (§0②). **Run the prop-clearance geometry check before printing final.** PETG/ABS for outdoor heat. $12 buy-bracket if no printer (verify it clears props at 100°). |
| Checkerboard calibration target (printed 9×6 inner-corner board on rigid backing) | 1 | $0–8 | $0–8 | Copy shop + foamboard, or Amazon calibration board | **Required before any range/bearing transfers** (§0③): feeds `scripts/calibrate_camera.py` → intrinsics + distortion for `flight.camera`. Print flat, mount rigid, known square size. A pre-printed board (~$8) is flatter than home print. |
| Dedicated compute BEC — **Matek BEC12S-PRO (9–55V→5.2V, 5A cont/9A peak)** | 1 | $16 | $16 | Matek / GetFPV | **Two-rail rule:** powers ONLY the Pi + camera, never off the FC BEC. **Buy the 5.2V Matek up front, NOT the 5.0V Pololu** — measured Pi 5 + Hailo load is only ~2.7A (5.5A was never the risk), but the Pi 5 undervolts at ~4.75V and a flat 5.0V rail loses that margin across wiring/connector resistance → mid-terminal CPU throttle → YOLO FPS collapse. 5.2V default fixes it at the source. Short 16 AWG + 1000µF cap + `usb_max_current_enable=1`. |
| SanDisk Extreme 128GB A2/U3 microSD (Pi OS + logs) | 1 | $18 | $18 | Amazon / Best Buy | Pi boot + vision stack + telemetry logging. **A2/U3** for OS random-IO (do NOT use an A1 High-Endurance card here). |
| † Official Pi 27W USB-C PD supply (bench) | 1 | $12 | $12 | PiShop / Adafruit | Bench power for headless dev/flashing before the drone BEC is wired; guarantees full 5A. |

**Subtotal (C): ~$400** (≈$388 if you own a USB-C PD supply)

---

## (D) Cables & PC connection

| Item | Qty | ~Unit | ~Line | Where | Why + key compatibility |
|---|---|---|---|---|---|
| Pi 5 camera FPC cable, 22-pin→15-pin (~200mm) | 1 | $6 | $6 | Adafruit / Arducam | **Pi 5 uses the narrow 22-pin CSI** — the camera's included cable will NOT fit. This bridges it. |
| FC↔Pi UART pigtail (JST-GH 6-pin → Dupont) | 1 | $6 | $6 | Holybro / GetFPV | The flight MAVLink link: **TELEM2 ↔ Pi GPIO14/15, both 3.3V, no level shifter, 921600 baud, TX/RX crossed.** |
| † USB-A → USB-C data cable | 2 | $8 | $16 | Amazon / Anker | One flashes PX4/QGC over the FC's USB-C; one is the bench MAVLink fallback. **Must be data, not charge-only.** |
| † USB-to-UART FTDI adapter, **3.3V** (CP2102 / SparkFun FTDI Basic) | 1 | $12 | $12 | SparkFun / Adafruit | Serial console into the Pi + FC debug. **Must be 3.3V** (5V damages the UART). |
| † USB-C/A microSD card reader (UHS-I) | 1 | $9 | $9 | Amazon | Flash Pi OS + pull ULogs off the FC card on your PC. |
| Holybro SiK Telemetry Radio V3 915MHz pair | 1 | $75 | $75 | Holybro / GetFPV | **Primary way to watch + command autonomous runs** — live MAVLink to QGC at the field (HUD, params, RTL/kill). FC TELEM1 ↔ PC USB. **915MHz = US; use 868MHz in EU.** *(Bought once — dedupes the two subsystem lists.)* |

**Subtotal (D): ~$124** (≈$87 if you own the USB cables, FTDI, and card reader)

> **Interceptor build so far (A+B+C+D): ~$1,089** *(pre-§0c full BOM — the lean §0c build-of-record is ~$740)*

---
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

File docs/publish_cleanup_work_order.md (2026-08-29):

# Pre-publication cleanup — EXECUTED 2026-08-19 (what remains is yours)

The full work order this file used to hold was executed on the
`claude/portfolio-data-github-cleanup-g792ae` branch (commits `7ea21c7`,
`5c40a96`, and the P2/P3 commit that carries this note; the original order
text lives in this file's git history). Done: password line deleted, the
retracted 12/16 kill-radius claim swept from every surface (PROGRESS, NEXT,
the contract, dashboard republished), root de-cluttered (goals/progress/next/
build_log under `docs/`, prompts under `.claude/`, launcher+bootstrap under
`scripts/env/`, intrinsics under `configs/`, `demo_out/` removed, CLAUDE.md
split into a 40-line summary + `.claude/ops.md`), README repackaged (image
rows, systems-engineering section with generated dashboard/MBSE screenshots,
results notes split out, CI badge, 60-second no-sim check, AI disclosure), and
the CI red fixed (the rescore gate test now skips loudly off the dev box; the
suite + drift gate verified green here against a pristine baseline).

## Remaining steps only the builder can do

**None of these need a Claude session** — each is a hands-on step at the PC,
in a phone browser, or at the sim machine. The same list is on the hosted
dashboard's "Waiting on you" panel.

1. **Rotate the VM's Linux password — FIRST, the repo is ALREADY PUBLIC**
   (`interceptor123` was in SETUP-GUIDE.md until 2026-08-19 and remains in
   public git history; it is a local-VM login, so low real exposure, but
   rotate it. Option A ruling: keep history — a rewrite would dangle 39+
   commit-hash evidence citations).
2. **Re-point the desktop launcher** if its shortcut targets the repo copy —
   the .bat now lives at `scripts/env/Launch Interceptor Sim.bat`.
3. ~~**Merge branch `claude/portfolio-data-github-cleanup-g792ae` into `main`**~~
   — **DONE 2026-08-29**, merged locally and pushed. It had sat unmerged for
   ten days; nobody noticed because the *published dashboard* was current
   while `main` was not, so every surface a human looks at said the work had
   landed. Found only because a dashboard republish hit a version conflict
   and the 2026-08-19 contract had to be recovered out of the published
   Artifact to see what was missing. Post-merge gate: `run_tests.sh` ALL
   GREEN (941 + 29 tests, both drift checks, every self-test pack).
   **Process fix owed: check for unmerged remote branches at session start.**
4. ~~Confirm the MIT license~~ — **DONE: builder confirmed MIT 2026-08-19**
   (recorded in `docs/publish_runbook.md` step 4). Weights stay out of the
   repo per `docs/license_notice_weights.md`.
5. **Set the GitHub About description + topics** with runbook-compliant
   wording (claim the design, never the unflown result — the claims scrub in
   `docs/publish_runbook.md` is binding).
6. **Re-shoot the hero GIF on the sim PC** (`scripts/build_demo.py` after a
   new hero flight — the caption fix is in; the retired assets were never
   replaced). The single highest-value README addition still open.
7. Optional: enable GitHub Pages on `/docs` so `dashboard.html` / `mbse.html`
   are clickable pages rather than raw files.

Note 2026-08-19: the hosted dashboard artifact now carries the MBSE view as
its own sheet (SHEET 5); the separate MBSE artifact link is superseded and
can be ignored. The emitted artifact build fails if `docs/mbse.html` is stale
(render order: `render_mbse.py` before `render_dashboard.py --artifact`).

Delete this file once the list above is done.

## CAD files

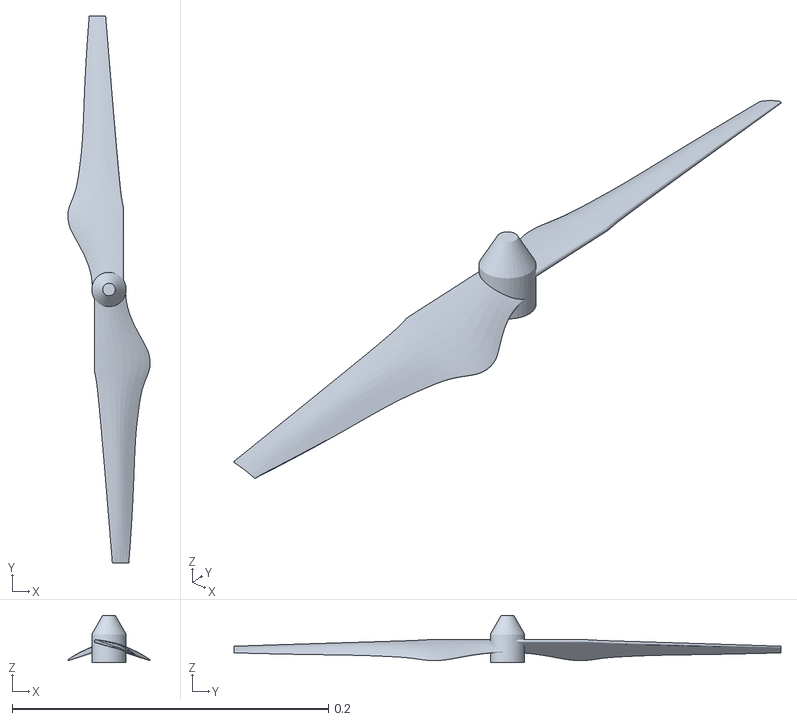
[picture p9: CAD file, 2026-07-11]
models/fpv_quad_enemy/meshes/1345_prop_cw.stl
0.052 x 0.346 x 0.03

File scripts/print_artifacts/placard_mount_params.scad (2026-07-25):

// =====================================================================
// placard_mount_params.scad -- SHARED PARAMETRIC DIMENSIONS
// AprilTag placard mount for the TBS Source One V6 target drone.
//
// Implements docs/placard_mount.md DECISION 3 (5.2 parts table, 5.3
// assembly, 5.4 frangibility, 6 dimensioned sketch).
//
// EVERY dimension below carries one of two tags:
//    [DOC  L<n>]  taken verbatim from docs/placard_mount.md, line <n>
//    [CHOSEN]     NOT specified anywhere in the doc; chosen conservatively
//                 here and repeated in the DIMENSIONS TO CONFIRM list at
//                 the bottom of this file. Confirm on the first print.
//
// Units: millimetres. Origin conventions are stated per part.
// Nothing here has ever been printed or fitted to hardware. Date 2026-07-25.
// =====================================================================

$fn = 96;                       // [CHOSEN] render smoothness

// ---------------------------------------------------------------------
// 0. Fasteners and stock
// ---------------------------------------------------------------------
m3_clear      = 3.3;   // [CHOSEN] M3 clearance hole. 3.2 is the textbook close
                       //   fit; 3.3 allows for FDM elephant-foot on a Z-axis
                       //   hole without reaming. Nylon M3x10 per [DOC L534/L535].
m3_head_d     = 6.4;   // [CHOSEN] counterbore for an M3 pan head (nylon pan
                       //   heads run ~5.5-6.0 mm) + print clearance
m3_head_h     = 2.4;   // [CHOSEN] counterbore depth
m3_nut_af     = 5.6;   // [CHOSEN] M3 nylon nut across-flats + clearance
m3_nut_h      = 2.6;   // [CHOSEN]

spar_od       = 4.0;   // [DOC L533] "2 x O4 x 0.5 mm wall carbon tube"
spar_id       = 3.0;   // [DOC L533] 4.0 - 2*0.5
spar_fit      = 0.35;  // [CHOSEN] radial clearance for the spar seat (printed
                       //   holes come out undersize; this is a slip fit, the
                       //   rubber bands do the clamping)

panel_t       = 5.0;   // [DOC L496] "5 mm paper-faced foamboard"
slot_w        = 6.0;   // [DOC L531] "6.0 mm x 110 mm slot" (0.5 mm per side on
                       //   a 5 mm panel)

// ---------------------------------------------------------------------
// 1. P1 -- INDEX DISC   [DOC L530, L679]
//    "O75 x 4 mm, 4 x M3 clearance on the frame's top-plate standoff
//     pattern, 24 x M3 holes on a O56 mm circle (15 deg steps), keyed
//     centre boss"
//    Origin: centre of the disc, bottom face on z = 0 (= the top plate's
//    upper surface, the datum used throughout placard_mount.md 6).
// ---------------------------------------------------------------------
disc_d        = 75.0;  // [DOC L530/L679]
disc_t        = 4.0;   // [DOC L530/L679]
index_pcd     = 56.0;  // [DOC L530] pitch circle of the 24 index holes
index_n       = 24;    // [DOC L530] 24 holes = 15 deg steps [DOC L721]
                       //   the shoe uses any DIAMETRICALLY OPPOSED pair [DOC L551]

// --- the frame interface. THIS IS THE BIGGEST UNKNOWN IN THE FILE. ---
// placard_mount.md L549 says only "the four top-plate standoff positions".
// The doc records the standoff LENGTHS (30/22 mm, L75) but NOWHERE records
// the standoff BOLT PATTERN of the TBS Source One V6 top plate, and no
// vendor drawing is cited anywhere in the repo.
standoff_dx     = 30.0; // [CHOSEN] MEASURE THIS ON THE FRAME BEFORE PRINTING
standoff_dy     = 30.0; // [CHOSEN] MEASURE THIS ON THE FRAME BEFORE PRINTING
standoff_rot    = 0.0;  // [CHOSEN] deg. Many 5" frames sit the top-plate
                        //   standoffs on the 45 deg diagonal -- if so, set 45.

// --- keyed centre boss [DOC L530 names it; gives no dimension] ---
boss_d        = 12.0;  // [CHOSEN] mates the shoe's pocket; carries the SHEAR so
                       //   the two index bolts see mostly clamp load
boss_h        = 3.0;   // [CHOSEN]
boss_key      = 2.5;   // [CHOSEN] depth of the flat that keys rotation
boss_fit      = 0.30;  // [CHOSEN] radial clearance in the shoe's pocket

disc_lighten  = false; // [CHOSEN] optional lightening pockets -- see the mass
                       //   note in DIMENSIONS TO CONFIRM #6
disc_light_d  = 9.0;   // [CHOSEN]
disc_light_pcd = 42.0; // [CHOSEN]
disc_light_n  = 6;     // [CHOSEN]

// ---------------------------------------------------------------------
// 2. P2 -- SHOE   [DOC L531, L555, L676-677]
//    "~110 x 40 x 24 mm: 6.0 mm x 110 mm slot 18 mm deep, two spar
//     saddles, two rubber-band hooks, 1.5 mm frangible web at the slot
//     base"
//    Origin: centre of the base, bottom face on z = 0 (it sits on the
//    disc's TOP face, i.e. global z = disc_t).
// ---------------------------------------------------------------------
shoe_h        = 24.0;  // [DOC L531]
shoe_w        = 40.0;  // [DOC L531]
slot_len      = 110.0; // [DOC L531]
slot_depth    = 18.0;  // [DOC L531] and [DOC L555] "the panel's lower 18 mm
                       //   sits in the slot"
base_t        = shoe_h - slot_depth;   // = 6.0  [DERIVED from DOC L531]
// GEOMETRIC CONSISTENCY CHECK (this is why the numbers above are trustworthy):
//   disc top      = 4 mm above the top plate            [DOC L530]
//   + base_t      = 6 mm                                [DERIVED]
//   = slot floor  = 10 mm above the top plate
//   which is exactly [DOC L499/L671] "panel bottom edge +10 mm above the top
//   plate". The doc's three independent numbers close. Good sign.

shoe_len      = 130.0; // [CHOSEN, DEVIATION from DOC L531's "~110"] the SLOT is
                       //   110 (as documented); the body is 10 mm longer at each
                       //   end to carry the band posts OUTBOARD of the slot, so a
                       //   band can cross the spar where the spar is exposed.
                       //   See DIMENSIONS TO CONFIRM #3.
wall_t        = 5.0;   // [CHOSEN] slot wall thickness. The doc's 40 mm width
                       //   would imply 17 mm solid walls (~125 g of PETG solid);
                       //   the 40 mm is treated as the BASE FLANGE envelope.

// --- spar saddle [DOC L531 "two spar saddles"; no dimensions given] ---
saddle_depth  = 1.5;   // [CHOSEN] how far the spar seat is sunk below the slot
                       //   floor, so the spar -- not the foam -- carries the load
                       //   ([DOC L486] "the foam never carries a mount load")
saddle_continuous = true; // [CHOSEN, DEVIATION] one continuous 110 mm seat
                          //   instead of two discrete saddles: more bearing
                          //   area, stiffer, one less print artefact. See
                          //   DIMENSIONS TO CONFIRM #4.

// --- the frangible web [DOC L531 "1.5 mm frangible web at the slot base"] ---
web_t         = 1.5;   // [DOC L531] -- KEPT AS DOCUMENTED, but see the
                       //   FRANGIBILITY WARNING below. This is the single most
                       //   important number to settle on the bench.
web_h         = 2.0;   // [CHOSEN] vertical extent of the necked band
web_relief    = 1.0;   // [CHOSEN] extra relief so the neck is a clean notch

// --- rubber-band posts [DOC L531 "two rubber-band hooks"; no dimensions] ---
post_x        = 60.0;  // [CHOSEN] outboard of the slot ends (slot ends at 55)
post_y        = 6.0;   // [CHOSEN] half-spacing; the spar passes between them
post_d        = 4.0;   // [CHOSEN]
post_h        = 12.0;  // [CHOSEN] tall enough that the band crosses ABOVE the
                       //   spar's crown and presses it into the seat
post_head_d   = 6.5;   // [CHOSEN] mushroom head so a #64 band cannot walk off
post_head_h   = 2.0;   // [CHOSEN]

// ---------------------------------------------------------------------
// 3. P8 -- SPAR END CAP   [DOC L537]
//    "2 x spar end cap ... placard_spar_cap.stl" -- NO dimensions given
//    anywhere. Everything here is [CHOSEN].
//    Origin: centre of the flange, flange bottom on z = 0.
// ---------------------------------------------------------------------
cap_plug_d    = spar_id - 0.15;  // [CHOSEN] 2.85 -- light interference in a
                                 //   3.0 mm ID tube; glue with a drop of CA
cap_plug_h    = 6.0;             // [CHOSEN]
cap_flange_d  = 5.5;             // [CHOSEN] slightly proud of the 4.0 mm tube
cap_flange_h  = 2.0;             // [CHOSEN]
cap_chamfer   = 0.6;             // [CHOSEN] chamfer on the exposed outer face
                                 //   (it is the part that hits the ground
                                 //   first). A chamfer, not a dome: a dome on a
                                 //   2 g part would need supports.
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

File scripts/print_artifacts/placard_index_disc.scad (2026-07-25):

// =====================================================================
// placard_index_disc.scad  --  P1, the 15-degree indexable disc
//
// docs/placard_mount.md 5.2 L530:
//   "Index disc, O75 x 4 mm, 4 x M3 clearance on the frame's top-plate
//    standoff pattern, 24 x M3 holes on a O56 mm circle (15 deg steps),
//    keyed centre boss | PETG | 8 g | print -- placard_index_disc.stl"
// docs/placard_mount.md 5.3 L549:
//   "P1 bolts to the four top-plate standoff positions with P5 (longer
//    nylon screws into the frame's existing 30 mm standoffs -- no new holes)"
// docs/placard_mount.md 6 L679:  "INDEX DISC (P1) O75 x 4, 24 holes @15deg"
// docs/placard_mount.md 8 L721:  index steps 0, +/-15, +/-30, +/-45, +/-60,
//                                +/-75, 90 deg
//
// WHY THIS PART EXISTS (placard_mount.md 5.6): it makes the placard's YAW
// ASPECT -- the thing the design is least certain about (3.3: the usable
// incidence cone is only about +/-32 deg at the deployed quad_decimate) -- a
// two-minute field change instead of a rebuild, without drilling the carbon.
//
// ORIGIN: centre of the disc, bottom face on z = 0, which is the top plate's
// upper surface (the datum for the whole 6 sketch).
//
// PRINT (all [CHOSEN]): PETG, 0.2 mm layers, 4 perimeters, 40 % infill, flat
// on the bed, NO supports. Printed flat, the 24 index holes and the 4 mounting
// holes are all Z-axis holes and come out slightly undersize -- m3_clear is
// 3.3 for that reason. NO STEEL AND NO MAGNETS anywhere in this assembly
// (placard_mount.md 5.4 L573 / 5.6 L642: the M10Q-5883 carries the compass).
//
// Nothing here has been printed or fitted. Read the DIMENSIONS TO CONFIRM
// list at the bottom of placard_mount_params.scad first -- item 2 (the frame's
// standoff bolt pattern) is a genuine unknown and it is in THIS part.
// =====================================================================

include <placard_mount_params.scad>

module key_boss(d, h, key, extra = 0) {
    // A cylinder with one flat -- the flat is what stops the shoe rotating on
    // the boss, so the two index bolts carry clamp load rather than shear.
    difference() {
        cylinder(h = h, d = d + 2 * extra);
        translate([d / 2 + extra - key, -d, -0.5])
            cube([d, 2 * d, h + 1]);
    }
}

module placard_index_disc() {
    difference() {
        union() {
            cylinder(h = disc_t, d = disc_d);                       // [DOC L530]
            translate([0, 0, disc_t])
                key_boss(boss_d, boss_h, boss_key);                 // [CHOSEN]
        }

        // 24 index holes on the O56 pitch circle, 15 deg apart.   [DOC L530]
        // The shoe uses any DIAMETRICALLY OPPOSED pair [DOC L551], which is
        // what makes the available settings 0, +/-15 ... 90 deg [DOC L721].
        for (i = [0 : index_n - 1])
            rotate([0, 0, i * (360 / index_n)])
                translate([index_pcd / 2, 0, -1])
                    cylinder(h = disc_t + 2, d = m3_clear);

        // 4 x M3 clearance on the frame's top-plate standoff pattern.
        // [DOC L530/L549] -- PATTERN ITSELF IS [CHOSEN], see TO-CONFIRM #2.
        rotate([0, 0, standoff_rot])
            for (sx = [-1, 1], sy = [-1, 1])
                translate([sx * standoff_dx / 2, sy * standoff_dy / 2, -1])
                    cylinder(h = disc_t + 2, d = m3_clear);

        // Optional lightening pockets (TO-CONFIRM #6, mass).
        if (disc_lighten)
            for (i = [0 : disc_light_n - 1])
                rotate([0, 0, i * (360 / disc_light_n) + 180 / disc_light_n])
                    translate([disc_light_pcd / 2, 0, -1])
                        cylinder(h = disc_t + 2, d = disc_light_d);

        // 0 deg index witness notch -- placard_mount.md 5.3 L552 tells you to
        // mark 0 deg with a paint pen so a field re-index cannot be got wrong.
        // A printed notch cannot rub off. [CHOSEN]
        translate([disc_d / 2 - 1.2, -1.0, disc_t - 0.8])
            cube([2.4, 2.0, 1.6]);
    }
}

placard_index_disc();

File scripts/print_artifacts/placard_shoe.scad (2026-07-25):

// =====================================================================
// placard_shoe.scad  --  P2, the SACRIFICIAL shoe.  PRINT FOUR.
//
// docs/placard_mount.md 5.2 L531:
//   "Shoe, ~110 x 40 x 24 mm: 6.0 mm x 110 mm slot 18 mm deep, two spar
//    saddles, two rubber-band hooks, 1.5 mm frangible web at the slot base
//    | PETG | 22 g | print -- placard_shoe.stl (x4: 1 + 3 spares)"
// docs/placard_mount.md 5.3 L551-552:
//   "P2 bolts to P1 through any diametrically-opposed pair of the 15 deg
//    holes. That bolt pair IS the index setting."
// docs/placard_mount.md 5.3 L555:
//   "Drop the bottom spar into the shoe's saddles; the panel's lower 18 mm
//    sits in the slot. Loop P7's two rubber bands over the spar into the
//    shoe hooks; add the hook-and-loop strap as a secondary."
// docs/placard_mount.md 5.4 L561-565: TARGET RELEASE 60-80 N.
// docs/placard_mount.md 6 L676-677: the shoe + "1.5 mm FRANGIBLE WEB".
//
// WHY THIS PART EXISTS (placard_mount.md 5.6 L646-648): it puts a 30-cent
// printed part in the crash load path of an aircraft the BOM itself describes
// as "the target takes the hard landings". It is MEANT to break. Print four.
//
// *** READ THE FRANGIBILITY WARNING IN placard_mount_params.scad. ***
// The documented 1.5 mm web is predicted to release at ~4.6 N applied at the
// panel's top edge, which is BELOW the doc's own 19 N worst flight load and
// 13x below its stated 60-80 N target. web_t is a parameter for exactly that
// reason: print one at 1.5 and one at 3.5 and run the 9-item-7 pull test.
//
// ORIGIN: centre of the base; bottom face on z = 0, which sits on the index
// disc's TOP face (global z = disc_t = 4 mm above the top plate).
//
// LOAD PATH (placard_mount.md 4.6 L486 "the foam never carries a mount load"):
//   panel -> bonded bottom spar -> saddle seat -> base -> 2 x M3 -> disc.
//   The slot's walls locate the panel; they do not carry it.
//
// PRINT ORIENTATION MATTERS HERE (all [CHOSEN]): PETG, 0.2 mm layers, 4
// perimeters, 30 % infill, printed FLAT (base on the bed, slot opening up),
// no supports needed. Printed this way the frangible web's layer lines run
// HORIZONTALLY, i.e. the web breaks along a layer boundary -- which makes the
// release load repeatable but LOWER than the bulk-material estimate. That is
// the direction you want for a sacrificial part, but it is another reason the
// pull test, not this file, sets the final web_t.
// NO STEEL, NO MAGNETS (placard_mount.md 5.4 L573 -- the M10Q-5883 compass).
// =====================================================================

include <placard_mount_params.scad>

wall_in  = slot_w / 2;              // inner face of each slot wall
wall_out = slot_w / 2 + wall_t;     // outer face of each slot wall
spar_seat_r = spar_od / 2 + spar_fit;
bolt_x   = index_pcd / 2;           // 28.0 -- the diametrically opposed pair
                                    // on the disc's O56 circle [DOC L530/L551]

module band_post() {
    // Mushroom post. A #64 band hooks over the pair of posts at one end of
    // the shoe and crosses ABOVE the exposed spar, pressing it into the seat.
    // [DOC L531] names "two rubber-band hooks" and gives no geometry -- all
    // of this is [CHOSEN], TO-CONFIRM #9.
    cylinder(h = post_h, d = post_d);
    translate([0, 0, post_h - post_head_h])
        cylinder(h = post_head_h, d1 = post_head_d, d2 = post_d);
}

module placard_shoe() {
    difference() {
        union() {
            // ---- base flange ----------------------------------------
            // 40 mm width is [DOC L531]; the length is [CHOSEN] 130 so the
            // band posts sit outboard of the 110 mm slot (TO-CONFIRM #3).
            translate([-shoe_len / 2, -shoe_w / 2, 0])
                cube([shoe_len, shoe_w, base_t]);

            // ---- the two slot walls, standing on the FRANGIBLE WEB ----
            // Above the web the wall is full thickness; through the web band
            // it necks to web_t. That neck is the designed break.  [DOC L531]
            for (s = [-1, 1]) {
                // necked web section, z = [base_t, base_t + web_h]
                translate([-slot_len / 2, s * (wall_in + wall_t / 2) - web_t / 2,
                           base_t])
                    cube([slot_len, web_t, web_h]);
                // full wall above the web
                translate([-slot_len / 2, s == -1 ? -wall_out : wall_in,
                           base_t + web_h])
                    cube([slot_len, wall_t, shoe_h - base_t - web_h]);
            }

            // ---- rubber-band posts, on the BASE (below the web) -------
            // Deliberately below the web so the band's load reacts straight
            // into the base and the disc: the band and the web are the TWO
            // INDEPENDENT frangible paths placard_mount.md 5.4 L567 asks for,
            // not one in series with the other.
            for (sx = [-1, 1], sy = [-1, 1])
                translate([sx * post_x, sy * post_y, base_t])
                    band_post();
        }

        // ---- spar seat along the slot floor -------------------------
        // [DOC L531] "two spar saddles"; implemented as one continuous seat
        // (TO-CONFIRM #4). Runs the full body length so the spar is supported
        // right out to where the bands cross it.
        translate([-shoe_len / 2 - 1, 0, base_t - saddle_depth + spar_seat_r])
            rotate([0, 90, 0])
                cylinder(h = shoe_len + 2, r = spar_seat_r);
        // ...and open the seat upward so the spar can be dropped in, not
        // threaded in [DOC L555 "Drop the bottom spar into the shoe's saddles"]
        translate([-shoe_len / 2 - 1, -spar_seat_r,
                   base_t - saddle_depth + spar_seat_r])
            cube([shoe_len + 2, 2 * spar_seat_r, spar_seat_r + 1]);

        // ---- 2 x M3 to the disc, on the O56 pair ---------------------
        // [DOC L530/L551]. Counterbored so the head sits BELOW the spar seat;
        // the spar bridges the 6.4 mm counterbore mouth.
        for (sx = [-1, 1]) {
            translate([sx * bolt_x, 0, -1])
                cylinder(h = base_t + 2, d = m3_clear);
            translate([sx * bolt_x, 0, base_t - saddle_depth - m3_head_h])
                cylinder(h = m3_head_h + 0.01, d = m3_head_d);
        }

        // ---- keyed pocket for the disc's centre boss -----------------
        // [CHOSEN] TO-CONFIRM #7. Carries shear so the index bolts do not.
        translate([0, 0, -0.01])
            difference() {
                cylinder(h = boss_h + boss_fit, d = boss_d + 2 * boss_fit);
                translate([boss_d / 2 + boss_fit - boss_key, -boss_d, -0.5])
                    cube([boss_d, 2 * boss_d, boss_h + boss_fit + 1]);
            }

        // ---- web relief notches --------------------------------------
        // Clean re-entrant corners at the neck so the break is a notch, not a
        // ragged tear, and so a slicer cannot bridge the neck solid. [CHOSEN]
        for (s = [-1, 1]) {
            translate([-slot_len / 2 - 1,
                       s * (wall_in + wall_t / 2) + web_t / 2, base_t])
                cube([slot_len + 2, wall_t / 2 + web_relief, web_h]);
            translate([-slot_len / 2 - 1,
                       s * (wall_in + wall_t / 2) - web_t / 2
                       - (wall_t / 2 + web_relief), base_t])
                cube([slot_len + 2, wall_t / 2 + web_relief, web_h]);
        }

        // ---- panel-entry chamfer on the slot mouth -------------------
        // [CHOSEN] makes fitting the panel in the field a one-hand job.
        // A square bar rotated 45 deg and sat on the wall's top inner edge
        // takes a ~1.2 mm chamfer off both faces of that corner.
        for (s = [-1, 1])
            translate([0, s * wall_in, shoe_h])
                rotate([45, 0, 0])
                    cube([slot_len + 2, 1.7, 1.7], center = true);
    }
}

placard_shoe();

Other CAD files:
models/fpv_quad_enemy/meshes/1345_prop_ccw.stl
models/x500_base/meshes/1345_prop_ccw.stl
models/x500_base/meshes/1345_prop_cw.stl
scripts/print_artifacts/placard_spar_cap.scad

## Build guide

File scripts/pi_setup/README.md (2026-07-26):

# `scripts/pi_setup/` — Pi 5 seeker-rig provisioning pack

Everything needed to bring up the **seeker rig's Raspberry Pi 5** for the tripod
field test, prepared **before the Pi arrives** so the first live run is a smoke
test, not a debugging session. This is the software half of the Tier-1 `seeker`
subsystem (`docs/project_state.json` `build_tab` steps **skr-01..skr-08**;
`docs/tripod_test_protocol.md` §1).

The camera is the **innomaker CAM-MIPIOV9281 V2** — a 1 MP **monochrome
global-shutter** OV9281, 1280×800, ~118° HFoV. Every camera-specific line below
cites the paper-check that cleared it: **`docs/camera_paper_check.md`**.

## What's in the pack

| File | What it is |
|---|---|
| `provision.sh` | Idempotent bring-up: apt deps, a `--system-site-packages` venv, the marker-guarded `config.txt` block (`dtoverlay=ov9281`, `camera_auto_detect=0`, `dtparam=uart0=on`), frees the UART for TELEM2, ssh/mDNS. `--dry-run` prints the full plan and changes nothing; `--revert` undoes it; `--cam-port 0` binds the other CSI connector. |
| `requirements-pi.txt` | The pinned pip deps that go **into the venv** (mavsdk, onnxruntime, pyapriltags). numpy/opencv/picamera2 come from apt — see the file's header for why. |
| `capture.service` | Optional systemd unit to run one `pi_capture.py` session on demand. |
| `selftest.sh` | Offline gate (exits 0/1, no hardware): `bash -n` + a `--dry-run` that asserts zero file changes and a full printed plan. |

---

## First-boot walkthrough

### 0. Flash the OS  (skr-01)

Flash **Raspberry Pi OS Bookworm, 64-bit** to the microSD with Raspberry Pi
Imager. In the Imager's advanced options, pre-set **hostname, user/password,
Wi-Fi, and enable SSH** — that gets you in headless with no monitor. Boot the Pi
5, **fit the active cooler** (skr-01 runs the CPU hard during the skr-07 thermal
soak), and seat the camera:

- The OV9281 board is **15-pin (1 mm)**; the **Pi 5 CSI port is 22-pin (0.5 mm)**,
  so the **Wonrabai 22→15 adapter cable is required** — narrow 22-pin end at the
  Pi (`docs/camera_paper_check.md` item 5). Ribbon contacts face the right way,
  connector latches down.
- **Which port: `CAM/DISP1`.** The Pi 5 has **two identical 22-pin CSI/DSI
  connectors**, silkscreened `CAM/DISP0` and `CAM/DISP1`, on the edge between the
  micro-HDMI connectors and the Ethernet port. `dtoverlay=ov9281` binds **camera
  connector 1 by default**, so a ribbon in `CAM/DISP0` enumerates **nothing** and
  gives you no error that says why
  (`raspberrypi.com/documentation/computers/camera_software.html`). If you must
  use the other port, re-provision with **`--cam-port 0`** (it emits
  `dtoverlay=ov9281,cam0`) rather than hand-editing `config.txt`.

### 1. Provision  (idempotent)

Clone the repo onto the Pi, then **preview** the plan (safe, changes nothing),
and **apply** it as root:

```bash
git clone <this-repo> ~/interceptor-sim && cd ~/interceptor-sim

# preview — prints every action, touches nothing
bash scripts/pi_setup/provision.sh --dry-run

# apply (needs root: writes /boot + /etc, installs apt)
sudo bash scripts/pi_setup/provision.sh --hostname interceptor-seeker

sudo reboot   # config.txt + cmdline changes only take effect after a reboot
```

What it changes, and why each camera line is safe:

- **`dtoverlay=ov9281` + `camera_auto_detect=0`** in `/boot/firmware/config.txt`
  — the OV9281 is a **mainline libcamera/kernel sensor**, no vendor driver to
  build; on Pi 5 / Bookworm you turn the auto-probe off so the overlay is
  honored (`docs/camera_paper_check.md` item 5). The base libcamera tree has no
  OV9281 tuning file — `uncalibrated.json` is fine here because **mono means no
  AWB/CCM to lose** (same item 5).
- **`dtparam=uart0=on`** — **this** is the line that creates `/dev/ttyAMA0` on a
  Pi 5, for the **TELEM2 MAVLink link to the flight controller** (3.3 V, 921600
  baud, TX/RX crossed; `docs/hardware_order_list.md` FC↔Pi UART;
  `project_state.json` `build_tab` brain, `MAV_1_CONFIG=TELEM2`). The GPIO14/15
  UART on a Pi 5 is **RP1 `uart0`, and it ships DISABLED** — `enable_uart=1`
  targets the *primary/console* UART, which on a Pi 5 is the debug-header
  `ttyAMA10`, **not these pins**. `enable_uart=1` is still written because it is
  the correct knob on pre-Pi-5 boards and is harmless here. **After the reboot,
  check it: `ls -l /dev/ttyAMA*` must now list `ttyAMA0` as well as `ttyAMA10`.**
  No FC is wired for the tripod day — this just gets the OS out of the way.
- **The serial console is stripped from `cmdline.txt`.** On a Pi 5 that console
  lives on the **3-pin debug header** (`serial0` → `ttyAMA10`), so this removes
  the **debug-header boot log and login shell** — it does *not* touch the GPIO
  UART, which never had a console there. Your surviving recovery consoles are
  **HDMI + keyboard (tty1)** and **SSH/avahi**. To get the debug console back:
  `sudo raspi-config nonint do_serial_cons 0` (or restore
  `cmdline.txt.interceptor-sim.bak`), then reboot. Also: **do not point MAVLink
  at `/dev/serial0` on a Pi 5** — it resolves to the debug header, not
  GPIO14/15. Use `/dev/ttyAMA0` explicitly.
- The block is **marker-guarded** (`# >>> interceptor-sim seeker provision >>>`),
  so re-running is a no-op and `sudo bash provision.sh --revert` strips it
  cleanly (originals are also backed up to `*.interceptor-sim.bak`).

Re-running `provision.sh` any time is safe — every step is a no-op when already
applied.

### 2. Verify the camera  (skr-02)

After the reboot, prove live frames at native resolution with the libcamera
stills tool (Bookworm's is `rpicam-still`):

```bash
rpicam-hello --list-cameras                 # OV9281 should enumerate
rpicam-still -t 1000 --width 1280 --height 800 -o /tmp/ov9281.jpg
```

You want a **1280×800** frame (`docs/camera_paper_check.md` item 2: 1280×**800**
vs the sim's 1280×960 — the 800-row sensor sees a shorter vertical strip).

**Two different failures, two different fixes — triage in this order:**

1. `--list-cameras` lists **nothing** / `No cameras available!` → the camera was
   never bound. **Check the CSI port first (30 seconds)**: the ribbon must be in
   **`CAM/DISP1`**, or re-provision with `--cam-port 0` if it is in `CAM/DISP0`
   (§0). Then: ribbon reversed / latch not down, plugged into the DSI half of a
   CAM/DISP port, or you have not rebooted since provisioning.
2. It **enumerates** but `rpicam-hello` then **times out / delivers no frames** →
   *this* is the out-of-date-libcamera case on Pi 5 / Bookworm — update it
   (`docs/camera_paper_check.md` item 5).

### 3. Smoke-test the capture script  (skr-03, skr-05)

First the **offline** self-test (no camera — proves the pipeline/layout):

```bash
.venv-pi/bin/python scripts/seeker/pi_capture.py --self-test    # exits 0/1
```

Then a **live** picamera2 pass on a static indoor scene, requesting the **≤1 ms
exposure** — the short global-shutter exposure is the whole reason for this
sensor and is what the field day's motion-blur read depends on
(`docs/camera_paper_check.md` item 3: `ExposureTime` is exposed in µs, sensor
floor ~40 µs ≪ 1 ms; make sure there's enough **daylight/gain** or the frame
goes dark):

```bash
.venv-pi/bin/python scripts/seeker/pi_capture.py \
    --source picamera2 --out sessions/smoke --n-frames 30 --exposure-us 1000
```

**Check `sessions/smoke/meta.json`** — this is the skr-03/skr-05 pass criterion:

```bash
python3 -c "import json;m=json.load(open('sessions/smoke/meta.json'));\
print('applied_us =',m['applied_exposure_us'],'meets_spec =',m['exposure_meets_spec'])"
```

`exposure_meets_spec` must be **`true`** and `applied_exposure_us` **≤ 1000**.
The value is read from the sensor's own per-frame metadata, so you are
*verifying* the ≤1 ms floor on this Pi, not assuming it. If it reads over 1 ms,
the sensor didn't apply the short exposure (usually too little light, or
`FrameDurationLimits` not lowered) — fix it now, indoors, not at the field.

> **Mono ≠ color caveat** (`docs/camera_paper_check.md` item 4): the deployed NN
> `drone_finetuned_quad_v2` was trained on **color** sim renders; these OV9281
> frames are **monochrome**, a domain shift that can only *lower* recall. Log it,
> don't "fix" it with a channel hack — the sanctioned fix is the real-data mono
> retrain (`docs/real_data_pipeline.md`). Relevant to curve (b), not to the ≤1 ms
> exposure check above.

### 4. (Optional) run captures via systemd

For hands-off field captures you can drive `pi_capture.py` from `capture.service`
instead of a terminal:

```bash
sudo cp scripts/pi_setup/capture.service /etc/systemd/system/
sudo systemctl daemon-reload
# tune per-pass values without editing the unit. --tag-size 0.35 is the ADOPTED
# placard edge (docs/placard_mount.md §2) — every tag-recovered range scales
# linearly in it — and --quad-decimate 1.0 is the planned tripod-day setting
# (ADR-0082). Both are stamped into meta.json.
printf 'SESSION=sessions/pass01\nNFRAMES=300\nEXPOSURE_US=1000\nEXTRA_ARGS=--calib calib.json --tag-size 0.35 --quad-decimate 1.0\n' \
    | sudo tee /etc/default/interceptor-capture
sudo systemctl start capture.service     # begin;  stop to end early
journalctl -u capture -f                 # watch
```

Edit `User=` and the `/home/pi/...` paths in the unit first if your flashed
username differs. Start it **on demand** — do not `enable` it for boot.

---

## The rest of the Build-tab bench items (skr-01..skr-08)

This pack directly covers **skr-01..skr-05**; the remaining three are bench tasks
that need real light/pixels or the flight controller and are pointed to here so
the walkthrough hands off cleanly:

| Step | Item | Where |
|---|---|---|
| **skr-01** | Flash Pi OS, boot, fit the active cooler | §0 above |
| **skr-02** | Seat the CSI ribbon (22-pin end at the Pi) into **`CAM/DISP1`**, prove live 1280×800 frames | §2 above (`rpicam-still`) |
| **skr-03** | Verify exposure control reaches **≤1 ms** | §3 above (`meta.json` `exposure_meets_spec`); `camera_paper_check.md` item 3 |
| **skr-04** | Paper-check the FoV — **DONE 2026-07-20** | `docs/camera_paper_check.md` (118° is **horizontal**; px/deg penalty ~15%, not 30%) |
| **skr-05** | Bench `pi_capture.py` indoors on a static scene, confirm ≤1 ms applied | §3 above (the live picamera2 pass) |
| skr-06 *(gate)* | Calibrate: ≥15 checkerboard views, RMS ≤ 1.0 px; **re-measure the delivered adjustable lens HFoV** here | `scripts/calibrate_camera.py`; `docs/tripod_test_protocol.md` §5; `camera_paper_check.md` items 1–2 |
| skr-07 | Bench the real Pi 5: sustained AprilTag fps + CPU-YOLO fps through a thermal soak | `docs/tripod_test_protocol.md` §7.3 (`pi5-emulation-gap`) |
| skr-08 | Run the NN shadow-scoring path on bench frames (v2 @640, conf 0.25) | `docs/tripod_test_protocol.md` §7.2 |

Two things to re-check the moment hardware lands (`camera_paper_check.md` "Net"):
(a) re-measure the **adjustable lens HFoV** against the checkerboard at skr-06;
(b) confirm `dtoverlay=ov9281` + `uncalibrated.json` actually brings up frames on
*this* Pi 5 / Bookworm (§2) — **from the connector the overlay binds (`CAM/DISP1`,
or `--cam-port 0` for the other one)** — before trusting any range number.

---

## Reversing the changes

```bash
sudo bash scripts/pi_setup/provision.sh --revert && sudo reboot
```

Strips the managed `config.txt` block, restores `cmdline.txt` from its backup,
and unmasks the serial-getty. apt packages and the venv are left in place
(harmless to keep). The revert **fails loudly** (non-zero) if the marker lines
are still there afterwards — a revert that removed nothing is never reported as
success.

If `config.txt` ever looks wrong (a bad hand-edit, an interrupted write), the
pristine pre-provision copy is one command away:

```bash
sudo cp -a /boot/firmware/config.txt.interceptor-sim.bak /boot/firmware/config.txt && sudo reboot
```

## Self-test (before you trust it)

```bash
bash scripts/pi_setup/selftest.sh     # exits 0/1, no hardware, safe on any box
```

Runs `bash -n provision.sh`, a sandboxed `--dry-run` that asserts the plan is
complete and that **no files were written and no venv created** (the proof that
`--dry-run` is genuinely side-effect-free, which is what makes it safe to preview
on this desk before running it on the Pi), and — via `--config-only` against a
sandbox boot dir — a **real apply/revert** that asserts the managed block lands
under `[all]`, that three applies leave exactly one block, that a hand-mutated
marker never duplicates it, that an *unterminated* block makes apply and revert
**refuse instead of deleting to end-of-file**, and that revert round-trips.

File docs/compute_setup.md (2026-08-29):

# Compute setup — the real interceptor's brains, end-to-end

*Companion to ADR-0015 (perception architecture) and ADR-0012 (hardware stack).
This file makes the compute concrete: who computes what, at what rate, over what
link, and — the load-bearing part — a **sourced, three-tier end-to-end latency
budget** you can later replace 1:1 with bench measurements. Covers docs/next.md items
**P-3** (compute split), **P-5** (onboard ML chip), **P-7** (latency budget).*

> **⛔ SUPERSEDED for the ONBOARD interceptor by the 2026-07-15 coded-dash pivot
> (ADR-0076 add #18, `docs/real_build_coded_dash.md`; live state: `docs/project_state.json`).**
> This doc describes the **parent-project ground-sensing half** — a ground Jetson
> track node + a cue radio ("~90-byte track message") + RTK ($400/pair) feeding a
> mid-course cue. The interceptor being built has **NO datalink and NO ground cue**:
> it flies a coded open-loop dash and the camera-only terminal acquires from a
> roughly-aimed dash; **RTK is CUT** (§0c binary-kill re-scope); the immediate air
> compute is **Pi 5 + AprilTag (CPU-real-time)**, with the Hailo HAT + markerless
> deferred. Read the latency-budget METHOD below as reusable; read the ground-rig
> ARCHITECTURE as parent-project context, not the current onboard build.

**Read this first if you're new to the terms** (one line each):
- **NPU** — "neural processing unit," a chip that runs neural-net math fast and
  cheap on power. The Hailo hat is an NPU.
- **TOPS** — "trillion operations per second," a rough size rating for an NPU. More
  TOPS = can run a bigger model or more streams.
- **TensorRT** — NVIDIA's tool that compiles a neural net to run as fast as possible
  on a Jetson. Always used on the ground node here.
- **Global shutter** — a camera that captures the whole frame at one instant (no
  skew when things move fast). Mandatory here (ADR-0012).
- **RTK / PPS** — RTK = a GPS trick that gets two receivers to agree to ~centimeters
  instead of meters; PPS = "pulse per second," a wire that makes both computers'
  clocks tick in lockstep with GPS time. Together they fix the "wrong place, wrong
  time" error that dominates cross-machine tracking (perception_design.md).
- **OOSM comp** — "out-of-sequence-measurement compensation." A cue that arrives
  late is stale; you slide it forward along its own velocity by its known age. The
  project already built this as `--cue-latency-comp`.
- **Latency vs. rate** — *rate* is how often a number arrives (Hz); *latency* is how
  old that number is when you act on it (ms). Both matter; they are not the same.

**The methodology (non-negotiable, from the builder):** every rate and latency below
gets three tiers — **BEST** (a datasheet or clean benchmark), **EXPECTED** (a
realistic integrated system), and **WORST-CREDIBLE** (thermal throttling, two
streams fighting for the chip, radio retries). **The sim is driven by EXPECTED, with
WORST as a stress case. A BEST number never sets a design margin.** Where sources
disagree, the pessimistic one is used and said so.

---

## 1. Pipeline map — who computes what, and how fast

Two computers. The **ground node** (a Jetson, power and weight are free) does the
heavy detection and builds the target *track*. The **air node** (Pi 5 + Hailo on the
drone) runs its own terminal seeker and the guidance. The link between them carries a
tiny **track message**, never video (that is the whole point of the split — Section 2).

### Ground node — Jetson Orin NX

```
2x global-shutter EO cameras (~2 m baseline)
      |  (each stream)
      v
[1] Small-object detector  (YOLOv8n/8s-class, TensorRT, run TWICE - once per stream)
      |
      v
[2] Stereo association + triangulation   (match the same drone in both views -> 3-D range)
      |
      v
[3] Track filter (Kalman)   ->  outputs filtered global-frame POSITION *and* VELOCITY
      |
      v
[4] Track message  ->  radio TX  at >=10 Hz
```

**The detector, honestly, run twice.** Peer-reviewed benchmark on Jetson Orin NX with
TensorRT: **YOLOv8n ~= 52 fps at 640x640 (FP16); YOLOv8s slower**, and
TensorRT cuts runtime 52-63% vs. plain PyTorch
([MDPI, *Computers* 2025, 15(2):74](https://www.mdpi.com/2073-431X/15/2/74)).
[Audit 2026-07-06: the paper tests FP16/FP32 only and names INT8 as *future work* —
the earlier "65 fps with INT8" figure is NOT supported by this source and is struck.
The load-bearing EXPECTED tier below uses the derated FP16 numbers, not INT8.] A
weaker Orin *Nano* gives YOLOv8n 16 ms / YOLOv8s 33 ms / YOLOv8m 50 ms per frame with
TensorRT ([arXiv 2409.16808](https://arxiv.org/html/2409.16808v1)) — a useful
pessimistic anchor. Newer YOLO26n on Orin NX 16GB is 4.13 ms FP16 / 3.49 ms INT8
*inference only* ([Ultralytics Jetson guide](https://docs.ultralytics.com/guides/nvidia-jetson/)).

Two honest deratings the datasheet fps hides:
- **Small objects need more pixels.** A drone at 100 m is a few pixels in a 640 crop.
  Real detection runs a larger input (~960-1280), which costs roughly 3-4x the
  compute — so a clean 52 fps single-stream drops toward ~12-15 fps.
- **Two streams share one GPU.** Running the detector on both cameras roughly halves
  what one stream gets (or you batch the two frames together — same total throughput).

Detector fps, three tiers, **per stream**:

| Tier | Detector fps (ground, per stream) | Basis |
|---|---|---|
| BEST | ~50-65 fps (YOLOv8n @640, INT8, one stream) | MDPI Orin NX |
| EXPECTED | **~15-20 fps** (YOLOv8s-class @~960-1280, small-object, two streams, detect-then-track front end) | MDPI derated for res + 2 streams |
| WORST-CREDIBLE | ~8-10 fps (thermal throttle at 25->15 W, contention) | derating; bench to confirm |

**This is fine, because of [3].** The Kalman filter *predicts* the target between
detections, so even a ~10 fps detector emits a smooth **>=10 Hz track** — and detection
mid-course is against a slow-changing, far target, the easy case. The mandatory output
is a **filtered velocity**, not just position: the project's own lab and Gazebo A/B
show emitting velocity vs. the drone differentiating a noisy position swings mean miss
**3.16 -> 1.01 m in the lab**; the paired Gazebo A/B confirms the direction with a
smaller effect (**EMIT 1.394 m vs. DIFF 1.808 m mean, Pk@2 75% vs. 50%**, n=8/arm,
worse-for-differentiate on 6/8 paired seeds — ADR-0015 2nd addendum). Velocity is a
few extra bytes; it is the #1 design lever in the whole perception half.

### Air node — Raspberry Pi 5 + Hailo-8/8L

```
Global-shutter mono camera (onboard)
      |
      v
[5] Detect (Hailo NPU)   - real ML, no ROS 2 (HailoRT Python API)
      |
      v
[6] Correlation tracker + alpha-beta/Kalman   (holds the lock through detection blinks)
      |
      v
[7] EKF fusion:  ground cue track  +  own camera bearing   ->  one target state
      |
      v
[8] Guidance (pro-nav / PIP) at 20 Hz  ->  MAVSDK  ->  TELEM2 UART  ->  PX4
```

**Verifying the "~35 fps / 29 ms" terminal claim (ADR-0015 / perception_design.md).**
The *raw* Hailo number is much faster: YOLOv11n on Pi 5 + Hailo-8 measures **104.9 fps
/ 7.75 ms hardware latency** over the Pi's single-lane PCIe Gen3 x1
([Hailo community official benchmark](https://community.hailo.ai/t/official-fps-benchmark-on-hailo-8-using-raspberry-pi-5/18873)),
and YOLOv8s on Pi 5 + Hailo-8L runs ~80-120 fps batched / ~107 fps ~= 8.4 ms
single-stream ([Seeed YOLOv8s on RPi5 + AI Kit](https://wiki.seeedstudio.com/benchmark_on_rpi5_and_cm4_running_yolov8s_with_rpi_ai_kit/)).
[Audit 2026-07-06: the previously-linked Seeed *multistream* page benchmarks YOLOv8**m**
(1-ch 77 fps), not YOLOv8s — corrected to the YOLOv8s page; if the exact 107 fps figure
can't be reconfirmed on the corrected page, treat it as a BEST-tier upper bound, not a
design number. The load-bearing end-to-end figure is the ~35 fps below, which stands.]
Two caveats keep us honest: the Pi 5 is **PCIe x1**, roughly *half* the host bandwidth
of Hailo's official x2 Model-Zoo numbers (same source); and those figures are the NPU
kernel alone. The **~29 ms / ~35 fps is the realistic *end-to-end*** figure once the
Pi CPU does capture + pre-processing + NMS post-processing + the detect-then-track
overhead. So:

| Tier | Terminal detect (air) | Basis |
|---|---|---|
| BEST | ~105 fps / ~8 ms (single model, NPU kernel) | Hailo community |
| EXPECTED | **~35 fps / ~29 ms end-to-end** (capture+pre+NMS+tracker on Pi CPU) | ADR-0015 / Hailo |
| WORST-CREDIBLE | ~15-20 fps (two streams — main + wide terminal cam — plus thermal) | derating |

**Hailo-8 vs. Hailo-8L:** the **8L = 13 TOPS** ($70 hat), the **8 = 26 TOPS** ($110
hat) ([Raspberry Pi AI HAT+](https://www.raspberrypi.com/news/raspberry-pi-ai-hat/)).
For one terminal detector the 8L clears >=30 Hz with ~2x margin. Recommend the
**Hailo-8** anyway: ADR-0015's acquisition-vs-terminal-FOV fix may add a *second*
wide-FOV terminal camera, and the 8 has the headroom to run two streams; the 8L does
not comfortably. Comfortably above the PX4 offboard **>=2 Hz "proof-of-life" minimum**
and the 20 Hz guidance loop ([PX4 Offboard](https://docs.px4.io/main/en/flight_modes/offboard)).

---

## 2. Track message spec — and why the link carries it but never video

The ground node sends one small message per update. Global-frame position so the drone
can place it in its own map; **filtered velocity** because that is the #1 lever; a
covariance diagonal so the EKF knows how much to trust it; a **source-GPS timestamp**
so OOSM comp can age-correct it; a track id and a quality flag.

| Field | Type | Bytes |
|---|---|---|
| Source-GPS timestamp (us) | int64 | 8 |
| Track id | uint16 | 2 |
| Global position (lat, lon x1e7; alt mm) | 3x int32 | 12 |
| Filtered velocity (vN, vE, vD) | 3x float32 | 12 |
| Covariance diagonal (sigma^2: 3 pos + 3 vel) | 6x float32 | 24 |
| Quality flag + source id + seq | 3x uint8 | 3 |
| CRC | uint16 | 2 |
| **Payload total** | | **~63 bytes** |
| + framing (MAVLink-style header/overhead) | | ~12 |
| **On-the-wire total** | | **~75-90 bytes** |

**Bandwidth math.** ~90 bytes = **720 bits/message**.
- At **10 Hz -> 7.2 kbps**. At **20 Hz -> 14.4 kbps**.

Now compare to what the two candidate links carry:
- **SiK telemetry radio (cheap):** serial 57 600 baud; over-air *air rate* 64 kbps,
  and enabling error-correction **halves** it to ~32 kbps net
  ([ArduPilot SiK config](https://ardupilot.org/copter/docs/common-3dr-radio-advanced-configuration-and-technical-information.html);
  [SiK V3](https://holybro.com/products/sik-telemetry-radio-v3)). Track at 10 Hz uses
  **~22% of a 32 kbps SiK link**; at 20 Hz ~45%. Fits, with room to share the link
  with normal MAVLink telemetry at 10 Hz.
- **MANET radio (jam-resistant, expensive):** Doodle Labs Mesh Rider is rated up to
  **80-100 Mbps** ([Doodle Labs](https://doodlelabs.com/blog/mesh-rider-technology-introduction/)).
  A 7.2 kbps track is **~0.01%** of it.

**Video, for contrast:** even a compressed 720p30 H.265 stream is ~2-4 **Mbps**. That
is **60-125x a SiK link's entire capacity — impossible** — and even on MANET it hogs
the channel, is easy to detect, and dies when jammed. **Sending a 90-byte track
instead of pixels is the architecture**: the cheap link is *trivially* enough for a
track and *categorically* can't do video. The heavy vision stays on the machine that
saw the photons.

---

## 3. End-to-end latency budget (P-7) — three tiers, sourced

How stale is the target information by the time it moves an actuator? Split into two
segments: the **cue-delivery chain** (ground camera -> the drone has fused the track) —
this is what the sim's cue-latency knob models — and the **onboard control chain**
(guidance -> PX4), which the sim models *separately* via its 20 Hz loop and PX4's
first-order response.

Link row uses **SiK-class** for EXPECTED (the cheaper, more likely, pessimistic
choice); a low-latency MANET link would roughly halve that one row.

| # | Stage | BEST (ms) | EXPECTED (ms) | WORST (ms) | Source / basis |
|---|---|---:|---:|---:|---|
| 1 | Exposure (global shutter, short to freeze motion) | 0.5 | 2 | 5 | [Arducam OV9281](https://docs.arducam.com/Raspberry-Pi-Camera/Native-camera/Global-Shutter/1MP-OV9281-OV9282/) — programmable exposure |
| 2 | Readout + capture to host | 3 | 8 | 17 | OV9281 60 fps@1280x800 -> <=1 frame = 16.7 ms |
| 3 | Detect, ground (incl. pre/post) | 10 | 30 | 70 | MDPI Orin NX v8n ~19 ms; arXiv Nano v8s 33 ms |
| 4 | Stereo association + triangulation | 1 | 5 | 15 | linear triangulation on Jetson (derived) |
| 5 | Track filter (Kalman update) | 0.2 | 1 | 3 | derived (few-state filter) |
| 6 | Serialize + radio TX (ground->air) | 5 | **40** | 90 | SiK: 90 B x8 / 32 kbps ~= 22 ms airtime + TDM half-duplex slot ([SiK config](https://ardupilot.org/copter/docs/common-3dr-radio-advanced-configuration-and-technical-information.html)); MANET ~= 5-20 ms |
| 7 | Radio RX + parse (air) | 0.5 | 2 | 5 | derived (small packet) |
| 8 | OOSM latency compensation | 0.1 | 0.5 | 2 | compute only; it *removes* staleness, not adds |
| 9 | EKF fusion (cue + bearing) | 0.2 | 1 | 3 | derived |
| | **Cue-delivery subtotal (compare to sim 0.12 s)** | **~20** | **~90** | **~210** | sum of 1-9 |
| 10 | Guidance cycle (20 Hz quantization) | 5 | 25 | 50 | half-to-full 50 ms period |
| 11 | MAVSDK setpoint (serialize + TELEM2 921600 + resend) | 2 | 8 | 20 | MAVSDK resends @20 Hz ([MAVSDK Offboard](https://mavsdk.mavlink.io/main/en/cpp/guide/offboard.html)) |
| 12 | PX4 ingest -> controller accepts setpoint | 5 | 15 | 30 | [PX4 Offboard](https://docs.px4.io/main/en/flight_modes/offboard) (500 ms failsafe timeout) |
| | **Onboard control subtotal** | **~12** | **~48** | **~100** | sum of 10-12 |
| | **Grand total (photon->PX4 acts)** | **~32** | **~138** | **~310** | excludes vehicle dynamics |

*Note: the vehicle's physical acceleration response — motors spinning up, attitude
changing — is a further ~0.3 s first-order lag (tau ~= 0.3 s, the value `guidance_lab.py`
already uses). That is dynamics, not information latency, so it is kept out of this
table and modeled by PX4 itself.*

**Jitter.** The mean is only half the story. The dominant jitter sources are the radio
(row 6: MAC contention, retries, TDM slot phase) and the detect-frame phase (rows
2-3). EXPECTED jitter ~= **+/-30 ms**; WORST bursts to +/-80 ms **plus full dropouts** (the
bursty Markov outages ADR-0015 already added). Jitter, not mean, is what breaks a
velocity estimate — which is exactly why the cue *emits* filtered velocity.

### Does the sim's 0.12 s +/- 0.05 s model survive?

Compare against the **cue-delivery subtotal**, not the grand total (the sim's cue knob
is only the ground->drone channel; the onboard rows are modeled by the sim's own 20 Hz
loop + PX4 lag).

- **EXPECTED cue-delivery ~= 90 ms** (SiK link) — or ~70 ms with a MANET link.
- The sim uses **120 ms mean**. That sits *between* EXPECTED (90 ms) and WORST
  (210 ms): the sim is **slightly pessimistic** vs. a realistic SiK build, and clearly
  pessimistic vs. MANET. Good — pessimistic is honest; it is not "cheating" the result.
- The sim's **50 ms jitter** is a shade *generous* vs. the smooth part (~+/-30 ms) but is
  the right order once radio retries and frame-phase are included; the real tail is
  captured better by the **bursty Markov dropout** (already implemented) than by
  widening the Gaussian jitter.

**Verdict: the 0.12 s +/- 0.05 s model SURVIVES — it is realistic-to-mildly-pessimistic,
so any Pk it produces is not flattered by an optimistic latency.** Corrections to adopt:

1. **Keep 0.12 s as the EXPECTED mean.** It straddles SiK-realistic and MANET, leaning
   pessimistic — the safe choice.
2. **Add a 0.20 s WORST-CREDIBLE stress tier** (`--latency-s 0.20`) and report Pk under
   it. Right now the sim never tests the throttled/contended tail; it should.
3. **Keep bursty Markov dropout ON and keep `--latency-jitter-s 0.05`.** The realism
   comes from the *shape* of the tail (outages), not a bigger symmetric jitter.
4. **Keep OOSM comp (`--cue-latency-comp`) available** — with a real 40-90 ms link it
   earns more than at the sim's current noise floor (ADR-0013 found it inconclusive at
   n=1); M5's Monte-Carlo has the power to settle it.

---

## 4. Compute-split rationale (P-3) — why hybrid wins, with numbers

Four ways to divide the work. Latency, cost, jam-exposure, weight for each:

| Split | Cue-delivery latency | Drone cost/weight | Jam behavior | Verdict |
|---|---|---|---|---|
| **A. All-onboard** (drone does everything, no ground rig) | Lowest — no link (~29 ms terminal only) | Highest onboard load | **Immune** (no link to jam) | But **no mid-course cue** -> hover-start kinematic cap ~3 m/s (ADR-0011). Can only catch slow/close targets. |
| **B. Central ground** (Jetson does all; drone is a thin actuator) | Highest — full ground pipeline **+ link both ways every cycle** | Cheapest/lightest drone | **Catastrophic** — link dies -> drone blind | Rejected: contradicts the comms-denied headline outright. |
| **C. Per-camera edge** (each ground cam has its own compute) | Removes 2-stream contention (row 3) but adds an intra-ground hop | Unchanged drone | Same as B on the air side | Overkill for 2 cameras; extra box + sync for little gain. Fold into ground node instead. |
| **D. Hybrid (CHOSEN)** — ground detects/stereos/tracks -> compact track; drone does terminal detect+track+fusion+guidance, finishes comms-denied | Mid-course uses ground cue (~90 ms — fine, slow phase); **terminal uses onboard (~29 ms, NO link)** | Drone carries only Pi+Hailo+cam (~50-100 g), not a Jetson | **Bounded** — jamming costs only the mid-course aid; the decisive terminal is jam-immune by design | **Wins.** |

**Failure-mode row (link jammed) — the deciding column, tied to ADR-0015's data:**

| Split | What happens when the link is jammed |
|---|---|
| A. All-onboard | No effect (no link) — but was never able to engage fast/far targets. |
| B. Central ground | Total loss: the drone has no autonomy. A hard cut mid-terminal = crash/miss. |
| C. Per-camera edge | Same as B for the drone. |
| **D. Hybrid** | **Graceful.** Drone dead-reckons to the predicted basket, opens a bounded seeker search, acquires in the last ~10-15 m or breaks off. The lab quantifies the cost: a jammer link-cut at 11.5 m is **-26% Pk@2 and +0.78 m mean miss** — the single worst *individual* degradation (ADR-0015 addendum, constraint c5), and still recoverable because the terminal is onboard. Design rule: `R_acquire >= R_cutoff + coast_margin`. |

**Why hybrid wins in one line:** it puts the power-hungry, heavy compute where power and
weight are free (the ground), keeps the drone light and cheap (+$70-110 of Hailo), and
**isolates the one phase that must survive jamming (the terminal) onto the one machine
that can't be jammed off it (the drone itself).** Everything ADR-0015 and docs/goals.md
argue for.

---

## 5. Parts + prices (2026, researched) — with stale-BOM flags

### Ground node

| Part | Choice | Price (2026) | Source |
|---|---|---|---|
| Compute | reComputer J4012 — Orin NX **16GB** + carrier + 128 GB NVMe (integrated) | **~$899** | [Seeed J4012](https://www.seeedstudio.com/reComputer-J4012-p-5586.html); [JetsonHacks](https://jetsonhacks.com/2023/01/23/seeed-studio-recomputer-j4012-jetson-orin-nx/) |
| — cheaper option | reComputer **Super J4011** — Orin NX **8GB** (117 TOPS Super) | ~$599 (8GB class) | [Seeed Super J4011](https://www.seeedstudio.com/reComputer-Super-J4011-p-6445.html) |
| — bare module ref | Orin NX 16GB **module only** (no carrier) | ~$989 | [ThinkRobotics](https://thinkrobotics.com/products/nvidia-jetson-orin-nx-module) |
| EO cameras x2 | global-shutter, ~2 m baseline (higher-res than the onboard cam for 100 m range) | ~$150-250 each -> **~$400** | (OV9281 1 MP ~$60 is too low-res at 100 m; budget a 2-4 MP GS cam + lens) |
| RTK base + PPS | ArduSimple simpleRTK2B (ZED-F9P, has TIMEPULSE/PPS) | **~$197** + antenna ~$50 | [ArduSimple](https://www.ardusimple.com/product/simplertk2b/); [ZED-F9P](https://www.u-blox.com/en/product/zed-f9p-module) |
| — or | Holybro H-RTK F9P | ~$189-325 | [Holybro H-RTK](https://holybro.com/collections/h-rtk-gps) |
| Rig / mount | ~2 m baseline bar + tripods | ~$150-300 | (COTS) |
| Link (ground end) | SiK V3 telemetry (day-proof, not jam-resistant) | **~$50** | [SiK V3](https://holybro.com/products/sik-telemetry-radio-v3) |
| — jam-resistant upgrade | Doodle Labs Mesh Rider MANET | **~$1,500-3,000+** | [Doodle Labs](https://doodlelabs.com/products/) |

**Ground-node total (EO-only, day-proof, SiK link): ~$1,600** (16GB J4012) — or
**~$1,300** with the 8GB Super J4011 + budget cameras. Add **~$1,500-3,000** for a FLIR
Boson 640 thermal (night + bird-rejection), and **~$1,500-3,000** if you swap SiK for a
MANET link.

### Air node (delta over the existing ADR-0012 ~$800 drone)

| Part | Choice | Price | Source |
|---|---|---|---|
| NPU hat | Raspberry Pi AI HAT+ **26 TOPS (Hailo-8)** | **$110** | [RPi AI HAT+](https://www.raspberrypi.com/products/ai-hat/) |
| — minimum | AI HAT+ **13 TOPS (Hailo-8L)** | $70 | same |
| RTK rover + PPS | ZED-F9P (shares the ground base; time-syncs to GPS) | ~$189-200 | [ArduSimple](https://www.ardusimple.com/product/simplertk2b/) / [Holybro](https://holybro.com/collections/h-rtk-gps) |
| Link (air end) | SiK V3 (pairs with ground) | ~$50 | [SiK V3](https://holybro.com/products/sik-telemetry-radio-v3) |

### Stale-BOM flags against ADR-0015

- **[!] "Jetson Orin NX ($400-600)" is STALE for the 16GB part.** After the 2024-25
  "Super" refresh, the 16GB module is ~$989 bare / ~$899 integrated (reComputer J4012).
  The **$400-600 band now only covers the 8GB** part (Super J4011). Use **~$899 (16GB)**
  or **~$599 (8GB)** as the current figure.
- **[!] The link price is understated.** ADR-0015 lists "SiK/MANET ~$20-100" and
  perception_design.md "~$20-300" — that is fine for **SiK (~$50)** but **MANET is
  ~$1,500-3,000+** (Doodle Labs). The two are not interchangeable: SiK = cheap +
  day-proof; MANET = jam-resistant + expensive. Budget them as separate lines.
- **[ok] Hailo +$70-110 is accurate** (AI HAT+ 13 TOPS $70 / 26 TOPS $110) — no change.
- **[ok] RTK/PPS enablers are real and cheap** (~$200/end, ~$400 for the shared pair);
  PPS is built into the ZED-F9P (TIMEPULSE), no extra hardware.

---

## 6. Bench-validation plan — one measurement per latency row

Ties to ADR-0015 build-plan step 4 (the five-number bench test). Each row of the
Section 3 budget has one concrete thing you'd measure on a bench so a real number
replaces the estimate 1:1:

| # | Row | One-line bench measurement |
|---|---|---|
| 1 | Exposure | Log the sensor's exposure register; strobe an LED, read the captured pulse width. |
| 2 | Readout/capture | Timestamp a hardware trigger vs. frame-arrived-in-userspace on the Jetson. |
| 3 | Detect (ground) | Wrap the TensorRT `infer()` in a timer over 1000 frames at the real input res, **two streams live**; report p50/p95. |
| 4 | Stereo/triangulate | Timer around the association+triangulation call on real dual-camera frames. |
| 5 | Track filter | Timer around one Kalman predict+update. |
| 6 | Radio TX | Timestamp-at-source vs. timestamp-at-receive over the real link, clocks PPS-synced; histogram the one-way delay. |
| 7 | Radio RX + parse | Timer from bytes-available to struct-parsed on the Pi. |
| 8 | OOSM comp | Timer around the age-advance; separately, measure residual position error vs. truth with comp on/off. |
| 9 | EKF fusion | Timer around one EKF update on the Pi. |
| 10 | Guidance cycle | Log guidance-loop period (already logged as sim-time in CSVs); on hardware, wall-clock it. |
| 11 | MAVSDK setpoint | Timestamp `set_velocity_ned()` call vs. the MAVLink packet on TELEM2 (scope or logic analyzer). |
| 12 | PX4 response | PX4 ulog: setpoint-received vs. setpoint-acted timestamps. |

Plus the two ADR-0015 bench extras: a **two-clock PPS time-sync** check (are both GPS
clocks within ~1 us?) and a **static stereo-vs-mono range-accuracy** measurement at
50-150 m (does sigma_R actually grow like R^2?).

---

## 7. Proposed ADR-lite block (for docs/decisions.md)

> ## ADR-0016 — Compute setup: hybrid split, track-message link, sourced latency budget (P-3/P-5/P-7)
> - **Context:** Make ADR-0015's split concrete — pipeline, rates, message spec, and a
>   sourced end-to-end latency budget the sim can adopt and a bench can later replace 1:1.
> - **Options:** all-onboard / central-ground / per-camera-edge / **hybrid**.
> - **Decision:** **Hybrid.** Ground Jetson Orin NX runs a two-stream small-object
>   detector (YOLOv8n/8s-class, TensorRT ~15-20 fps/stream realistic) -> stereo
>   triangulation -> Kalman track emitting **filtered position AND velocity** at >=10 Hz.
>   Air Pi 5 + **Hailo-8 (26 TOPS, $110)** runs terminal detect (~35 fps/29 ms
>   end-to-end) + tracker + EKF fusion + 20 Hz guidance -> MAVSDK/TELEM2 -> PX4. Link
>   carries a **~90-byte track message** (7.2 kbps @10 Hz), never video.
> - **Why:** heavy compute where power/weight are free; a cheap link trivially carries a
>   track and categorically can't carry video; the jam-critical terminal is onboard =
>   jam-immune. Failure-mode: only hybrid degrades gracefully when jammed (dead-reckon +
>   seeker search), vs. total loss for central-ground.
> - **Latency finding:** EXPECTED cue-delivery ~= **90 ms** (SiK) / ~70 ms (MANET), WORST
>   ~210 ms. The sim's **0.12 s +/- 0.05 s cue model SURVIVES** — realistic-to-mildly-
>   pessimistic. Add a **0.20 s WORST stress tier**; keep bursty dropout + OOSM comp.
> - **BOM flags:** Orin NX 16GB is **~$899** now (ADR-0015's $400-600 is stale, was the
>   8GB/pre-Super price); **MANET ~= $1,500-3,000+**, far above the "$20-100" link line.
>   Hailo +$70-110 and RTK/PPS ~$400/pair confirmed. **Ground node ~$1,600 EO-only.**
> - **Date:** 2026-07-05. (No council — synthesis of ADR-0012/0015 + 2026 sourcing;
>   reversible; every number bench-measurable per Section 6. [Date corrected from
>   2026-07-06 to match ADR-0016 in decisions.md; committed 2026-07-05 evening.])

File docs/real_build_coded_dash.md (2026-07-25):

# The real interceptor: coded-dash → camera-only (build reference)

*Consolidates the 2026-07-15 real-build pivot (ADR-0076 add #18a–c, memory
`real-build-pivot`). This is the operating model the physical interceptor in
`docs/hardware_order_list.md` actually flies — it supersedes the cue-guided /
FusedTrack architecture of `deployment_phases_design_brief.md` and
`phase2_sim_to_real_plan.md` for the onboard interceptor (those remain the
reference for the parent project's ground-sensing half).*

## Operating model (one line)

**A CODED, open-loop DASH pointed roughly at the target, then a CAMERA-ONLY
proportional-navigation terminal to impact.** No ground-sensor cue, no datalink
mid-course, no cue-fusion / handoff-gate / coast-search. The dash is
hand-programmed (or fired on a rough ground bearing); the onboard camera does the
rest.

Phase machine (in `scripts/m4_intercept.py --coded-dash`, and the target of the
`flight/` port): `TAKEOFF → CODED_DASH → ENGAGE → BREAKOFF → LAND`.
- **CODED_DASH** — fly a fixed heading + speed. Auto-heading solves the
  collision-lead azimuth from the *known* launch kinematics (a pre-flight
  constant, not a live sensor read — honesty boundary intact); `--dash-heading-deg`
  overrides it (the "human points it" case). Hand off the instant the detector
  holds 5 consecutive fresh detections.
- **ENGAGE** — the unchanged camera-only pro-nav terminal: `a = N·Vc·λ̇` on the
  full-attitude-derotated LOS. `BREAKOFF` past closest approach; `LAND`.

## Why the pivot (what it fixed)

The sim spent weeks on the realistic-quad **r2l** failure inside the cue-guided
pipeline (ADR-0076 add #13–#17). The real interceptor has **no cue**, so much of
that debugging was on machinery the hardware won't have. Testing the actual flight
architecture (coded-dash) both re-scoped the problem and *improved* it.

### Validation — paired A/B (quad_v2, seed 123, weave, n=8/dir, geometry byte-identical)

| architecture | dir | acquire | Pk@2.5 m | miss mean (m) |
|---|---|---|---|---|
| cue-guided (full deployment cfg) | l2r | 8/8 | 8/8 | 0.61 |
| cue-guided | r2l | 8/8 | **0/8** | 3.97 |
| **coded-dash** | l2r | 8/8 | 8/8 | 1.37 |
| **coded-dash** | r2l | 8/8 | **5/8** | 2.68 |

The saga's "r2l 0%" was **0/8 inside the 2.5 m Pk gate** (it engaged 8/8 but at
3.25–4.27 m), *not* a no-engagement null. Dropping the fused dash (which
under-committed east because the aspect-biased r2l bearing corrupted its aim)
lifts **r2l 0/8 → 5/8 @Pk, mean 3.97 → 2.68 m**. Cost: l2r loosens 0.61 → 1.37 m
(the cue genuinely helped l2r) but stays 8/8 @Pk. Net: the 6.5× l2r/r2l asymmetry
collapses to 2×; combined Pk@2.5 m **8/16 → 13/16**. *~~This is the number that
matters for the hardware — no cue exists on it.~~* *[caveat — ADR-0076 add #18g/#18h:
the 13/16 combined is largely open-loop DASH BALLISTICS; a dash-only control scored
the same, and no camera-guided 3D-quad intercept exists in sim. The dash AIM is the
real result; the camera terminal added ~nothing. See `docs/project_state.json`.]* Data:
`logs/mc_coded_dash_qv2_weave.csv` vs `logs/mc_quad_v2_s123_weave.csv`;
`scripts/coded_dash_summary.py` reproduces the table.

### Robustness — the hand-programmed dash carries operator aim error

Heading-error sweep (`--dash-heading-err-deg`, 48 flights over 0/+15/+30°):

| heading err | l2r Pk@2.5 | l2r miss | r2l Pk@2.5 | r2l miss |
|---|---|---|---|---|
| 0° | 8/8 | 1.37 | 5/8 | 2.68 |
| +15° | 8/8 | 2.33 | 7/8 | 1.60 |
| +30° | 0/8 | 3.25 | **8/8** | **0.78** |

1. **Acquisition survives ≥30° aim error** — all 48 flights acquired and
   engaged. The dash only has to point *roughly* right~~; the camera terminal
   finds the target once it enters frame. This is the core viability result~~.
   **⛔ SUPERSEDED (ADR-0076 add #18g/#18h — see the retraction banner below):**
   "acquired and engaged" means the handoff state machine fired; the gt-consistent
   audit showed those ENGAGE detections were overwhelmingly PHANTOM (~0 in-flight
   approach recall, add #18i; #18k localizes the wall to dash-pitch pointing).
   The camera terminal did NOT find the target. What this sweep actually shows:
   the **OPEN-LOOP DASH AIM tolerates ≥30° heading error** — dash-aim robustness,
   not perception proof (`docs/project_state.json` launch_aim).
2. **l2r Pk tolerance ≈ 15–20°.**
3. **r2l improves monotonically with east bias** → sub-meter 8/8 @0.78 m by +30°.
   So the r2l residual is a *systematic, fully-correctable east-aim deficit*, not
   a stochastic perception floor. **[⛔ per add #18g/#18h the 0.78 m is open-loop
   dash ballistics — aim-calibration evidence, not camera-terminal performance;
   "not a perception floor" is retracted: the flight-dynamic perception wall
   (add #18k) IS the binding wall.]**

## The portable core — `flight/` (runs identically in sim and on the Pi)

Pure Python + `math`, **no gz / ground-truth / cue imports** → the same code
flies in Gazebo SITL and on the real Pixhawk-6C/PX4 + Pi5. 25 tests
(`scripts/run_tests.sh`), and `m4_intercept.py` already calls `flight.guidance`
for its coded-dash aim (byte-identical).

| module | what it is | hardware role |
|---|---|---|
| `flight/geometry.py` | camera→body→NED LOS derotation (full attitude + mount tilt), `wrap_pi` | turns a camera bearing + EKF attitude into an inertial LOS azimuth |
| `flight/estimator.py` | alpha-beta (g-h) tracker for the λ and R channels + Kalata adaptive gains | smooths the noisy, intermittent LOS/range for pro-nav |
| `flight/guidance.py` | `collision_lead_heading` (coded-dash aim), `closing_speed`, `pronav_lateral_accel` (`a=N·Vc·λ̇`) | the dash aim + the terminal guidance law |
| `flight/camera.py` | pinhole + Brown-Conrady lens model; `pixel_to_ray` / `pixel_to_bearing` | **undistorts** the wide-M12 pixel before the bearing (see below) |

The perception→guidance chain on hardware:
`pixel (YOLO/AprilTag) → CameraModel.pixel_to_ray → derotate_bearing_lambda →
AlphaBetaFilter → pronav_lateral_accel`.

## Camera pipeline (calibrate → model → bearing) — closed and validated

The real Arducam AR0234 + ~100° M12 lens **barrel-distorts**; a bearing from a raw
pixel is wrong toward the frame edges (>1° at the edge on a representative model)
→ corrupts the LOS. So the seeker must undistort first.

- `scripts/calibrate_camera.py` — checkerboard → intrinsics + Brown-Conrady
  distortion (`--live` or `--images`). **`--self-test`** validates the whole
  calibration math on synthetic data (recovers fx/fy/cx/cy + k1/k2 exactly,
  rms 0.0 px) and confirms `flight.camera` loads the result — CI-gateable before
  the hardware exists.
- `flight.camera.CameraModel.from_json(calib.json)` loads it; zero-distortion is
  the Gazebo pinhole special case (byte-identical if wired into the sim seeker).

## Hardware mapping (`docs/hardware_order_list.md`, ~$1,089)

> ⚠️ **SUPERSEDED totals/parts:** this table predates the §0c binary-kill lean re-scope
> (`docs/hardware_order_list.md` §0c, 2026-07-15) — interceptor **~$740**; camera = **OV9281 mono
> GS wide** (AR0234 below = upgrade path only); **Hailo HAT DEFERRED** — first kills fly the
> AprilTag baseline on the Pi 5 CPU. Current state: `docs/project_state.json`.

| real part | why it transfers |
|---|---|
| **Pixhawk 6C Mini / PX4** | the exact stack the sim validated — params + MAVLink/OFFBOARD guidance transfer directly |
| Pi 5 8GB + Hailo-8L | YOLO11n @640 on the NPU; CPU free for MAVLink *(HAT deferred to the markerless phase, §0c)* |
| Arducam AR0234 global-shutter + ~100° M12 | the terminal seeker (AprilTag was the sim stand-in); calibrate with `calibrate_camera.py` *(upgrade path; lean build = OV9281 mono, §0c)* |
| adjustable up-tilt / **prop-clearance** bracket | prop-clearance per §0②. **A FIXED up-tilt IS the committed pointing decision (builder 2026-07-17; adaptive tilt REJECTED for simplicity)** — the tilt attacks the ACQUISITION wall (75% of terminal ticks have the target out-of-frame under the dash pitch), sized to the airframe's measured steady dash pitch (~25-40°, from the first real dash ULog → print an adjustable 10-30° bracket and lock it). The prior up15 NULL (ADR-0067/0068) was a cue-era terminal-PARITY test, a different context. Since a dash-pitch tilt exceeds the flush mount's ~11° prop clearance, the tilt requires the nose-cantilever/boom geometry (ADR-0088; constraint `forward-camera-boom`). See the `pointing` stage in `docs/project_state.json`. |
| ArduPilot GPS quad, AUTO box | the target (straight legs ≥2 m/s) |

## Build path when the hardware arrives (open, largely hardware-gated)

1. **Frame source** — Picamera2/libcamera → the seeker (`Measurement` seam).
2. **MAVSDK over TELEM2 serial** (921600) + PX4 params + a **safety module**
   (RC kill live, geofence, dash timeout) + a wall-clock (not sim-clock) audit.
3. **AprilTag on the Pi** = the flight baseline seeker; then the Hailo YOLO path
   (needs a real-data retrain). Do the prop-clearance geometry check first.
4. **`real_flight.py`** — wire `flight/` + MAVSDK + frame source into
   TAKEOFF → coded dash → camera-terminal ENGAGE → breakoff → land.
5. **`field_score.py`** — CPA from the two GPS logs, the real-world miss metric.

## Goal-condition results + where the sim work lands (2026-07-15, ADR-0076 add #18e/f → CORRECTED by #18g)

> **⛔ RETRACTED (Fable adversarial verification, ADR-0076 add #18g).** An earlier version of
> this section claimed the guidance was "solved" and the camera terminal produced a sub-meter
> r2l kill. That was a MIRAGE: the sub-meter r2l numbers are the OPEN-LOOP DASH's own
> ballistics, NOT camera guidance — a control arm that never engaged the camera scored the same
> ~0.54 m, and the ENGAGE detections were phantom (LOS error ±120–140°). **No camera-tracked <1 m
> intercept of the 3D quad exists in the dataset.** What is real: the crossing-bias is a good
> OPEN-LOOP AIM CALIBRATION (r2l 3.46 → dash 0.54 m). The real wall is that the detector has
> **~0 recall on the APPROACHING target** (2 real vs 1187 phantom detections on approach across
> 63 flights); the phantom is the false-handoff hazard, not the acquisition blocker, so
> "prop-clearance fixes acquisition" is UNTESTED. Next sim test: camera-forward × coded-dash
> (`scripts/experiments/cam_forward/` + `--cam-fwd-offset-m 0.40`) — see add #18g. *(Since FLOWN →
> add #18h: phantom removed at source, approach recall still ~0 — prop-clearance is NOT the
> acquisition fix; the wall is flight-dynamic pointing, add #18k.)* The
> superseded text below is kept only for the audit trail.

The goal crisped to: intercept a **≥20 mph (~9 m/s)** target to **<1 m**, camera-only. *(METRIC
SUPERSEDED same day, 2026-07-15: success re-scoped to a BINARY contact KILL confirmed on seeker
video + phone slow-mo + both ULogs, NOT a measured <1 m CPA — literal <1 m @9 m/s is graveyarded;
see `docs/hardware_order_list.md` §0c + `docs/project_state.json`.)*
The sim was pushed hard on the actual goal geometry (a straight line @9 m/s, not the
easier weave). ~~Honest landing:~~ *(superseded — see the retraction above)*

- **GUIDANCE / aim is largely SOLVED.** The straight-line baseline missed by ~3.4 m
  because it unmasks a direction-dependent **aspect-biased aim** (ADR-0056). Built
  `--dash-crossing-bias-deg` — a per-direction correction whose sign auto-keys on the
  crossing direction (dash × `--target-vel`, a pre-flight constant, honest, no gt).
  **Validated on 2 seeds: r2l median 0.72 m, 9/16 within 1 m, best 0.37 m (contact)** —
  the markerless *aim* can be corrected to the edge of kill range with no perception
  change. But the correction is **speed/aspect-specific** (the +30° tuned for 9 m/s
  over-corrects at 5 m/s), which points at a real-data detector — not a hand-tuned
  bias — as the robust fix.
- **PERCEPTION is the wall, and it's HARDWARE/real-data-gated (proven, not assumed).**
  l2r locks only ~half the time because the detector locks the **own-prop phantom**
  (median implied range 1.6 m) while the real target at 16 m is barely seen. Every
  software separator fails — a handoff range-plausibility gate is NULL (phantom
  overlaps the real detections in implied range, ADR-0076 add #13), the phantom-free
  retrain is NULL in flight (add #18d), ~12 prior levers NULL. **The fix is the
  hardware prop-clearance mount (§0② of the BOM — remove the phantom at the source)
  plus a real-data-trained detector** (no aspect-bias, no prop-lock).

## Honest open items

- **Success criterion (current):** BINARY KILL on video + both ULogs (§0c re-scope,
  2026-07-15) — not a measured <1 m CPA.
- ~~**The markerless kill is guidance-ready but perception-blocked.** At 9 m/s, r2l
  reaches contact on the good flights (not reliably); l2r is phantom-blocked. The two
  remaining walls — l2r phantom-acquisition and r2l bearing-tightening — are the known
  perception limits that need **hardware (prop-clearance) + real-flight data**, not
  more sim levers. The sim has extracted the guidance win and named the hardware
  requirements; the next real progress is BUILDING (R4+).~~
  **⛔ SUPERSEDED (ADR-0076 add #18g/#18h/#18k — see the retraction banner above; current
  state: `docs/project_state.json`):** no camera-tracked <1 m intercept of the 3D quad
  exists; the 9 m/s r2l contact-range flights were open-loop dash ballistics (#18g,
  confirmed by the #18h dash-only control — one hit 0.32 m with ZERO real ENGAGE
  detections). The binding wall is FLIGHT-DYNAMIC pointing (~40° nose-down dash pitch
  parks the target at the frame-top edge; detector 100% static 8–22 m, 0.8% in flight —
  #18k) → adaptive camera tilt (#46/ADR-0065) is the dominant, sim-testable lever; the
  real-data detector is a HYPOTHESIS for the outdoor-appearance gap; prop-clearance
  removes the false-handoff phantom hazard only, not acquisition.
- **Everything past `flight/` is untested** until the hardware exists — the
  frame source, serial MAVSDK, and the real seeker are hardware-gated. The
  guidance core (incl. `--dash-crossing-bias` mechanism) is validated and transfers;
  its magnitudes must be re-tuned on real data.

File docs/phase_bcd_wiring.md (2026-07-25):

# Wiring note — Phases B/C/D intercept-accuracy levers (pre-coded, default-OFF)

> **Status: PRE-CODED, OPT-IN, NOT SIM-VALIDATED (2026-07-21).** These three
> modules implement Phases B, C, D of `docs/intercept_accuracy_levers.md` as
> self-contained, flag-gated `flight/` core modules with unit tests. They are
> **built ahead of the sim A/B on purpose**: Phase A (loft-then-dive pointing)
> must land and validate first — every lever here is "only once framed" (levers
> doc). This note is the exact hook-up for the head/builder to A/B each behind a
> flag in `scripts/m4_intercept.py`. **Nothing here edits `m4_intercept.py`,
> `guidance.py`, or `estimator.py`** — they compose as wrappers.

| Module | Phase | Flag (proposed) | One line |
|---|---|---|---|
| `flight/fov_guidance.py` | B — hold the residual | `--fov-hold` | Vertical FOV-hold: IBVS pixel-centering + look-angle barrier + a pitch-headroom accel cap, on the pitch-coupling axis. |
| `flight/range_fusion.py` | C — sharpen ZEM/t_go | `--range-fusion` | bbox size-range prior `R=fx·W/w`, closing rate, and τ, fused as a coarse prior into the range channel. |
| `flight/terminal_coast.py` | D — endgame | `--terminal-coast` | τ-armed freeze-the-LOS-rate coast through the sub-1 m camera blind window. |

All three are **byte-identical no-ops when their flag is off** (and inert on
coasting/no-detection ticks even when on), so they can land dark and be A/B'd
one at a time.

---

## Honesty status (read before wiring — each adds a pixel→loop path)

Every module reads **only** camera pixels/bearing + own-state EKF (attitude,
velocity, sim clock). No `gt_*`, no datalink. But each introduces or rides a
**new pixel-into-guidance path**, which per the CLAUDE.md honesty boundary
**re-earns the numeric no-cheat audit** the same way any new guidance path does:

- **B** steers the vertical channel on the target's **image position** (`eps_v`
  from `meas_xyz` / the undistorted pixel). New pixel→command path.
- **C** steers the **range channel** on the detector **bbox width**. New
  pixel→range path. `W ≈ 0.3 m` is a *pre-briefed known constant* (same status
  as the AprilTag side length), not a measurement of this target.
- **D** adds no new sensor, but its **τ arm signal rides C's bbox path**, so the
  B+C+D composition is audited as one.

Run the audit (grep the guidance path for `gt_`, confirm `meas_xyz`/`bearing`/
`w_px` are the only exogenous inputs, confirm every `t` is a sim-clock value)
**before any A/B number is quoted** — same drill as `derotate_bearing_lambda`.

---

## Phase B — `flight/fov_guidance.py` behind `--fov-hold`

**What it is.** The wedge sets the *static* camera-elevation bias; this absorbs
the *dynamic* residual of the +40°→−35° dash pitch swing that a fixed wedge
cannot track. It is formulated on the **vertical** (pitch-coupling) axis — the
measured failure is vertical (target parks at the frame **top**), so the
horizontal law `a=N·Vc·λ̇` is left completely untouched.

**Three pieces** (`augment_pronav` returns all in a `FovHoldCommand`):
1. `ibvs_centering_accel` — gentle always-on `a_up = −k_center·Vc·eps_v`
   (position-only image feedback; for small angles `eps_v == (v−cy)/fy`).
2. `fov_edge_barrier_accel` — quadratic soft barrier, off inside `engage_frac`
   of the usable half-FOV, hard push-back near the edge.
3. `pitch_headroom_accel_cap` — the **look-angle CONSTRAINT**: the max forward
   accel whose steady quad pitch `θ=−atan(a/g)` keeps the target in-frame given
   where it sits *now*. This is the hook that co-sizes the accel-capped dash
   with the wedge (Phase A/B joint sizing).

**Wire-up in `m4_intercept.py` (ENGAGE, ~line 2812 where `a_cmd` is formed).**
Construct the config + imports ONCE (hoist out of the per-tick loop — review
finding 7), e.g. next to the filter construction ~line 2187:
```python
if args.fov_hold:
    from flight.fov_guidance import augment_pronav, FovHoldConfig, half_fov_from_intrinsics
    fov_cfg = FovHoldConfig(half_vfov_rad=half_fov_from_intrinsics(fy, height))
    FOV_VERT_MAX = args.fov_vert_max     # dedicated clamp, NOT V_VERT_MAX (below)
    v_up = 0.0
```
then per ENGAGE tick:
```python
# after: a_cmd = N_PRONAV * vc * lambda_dot_hat  (unchanged horizontal law)
if args.fov_hold and meas is not None and detected:
    pitch_rad = math.radians(state.pitch_deg) if state.pitch_deg is not None else None
    fov = augment_pronav(a_cmd, meas.meas_xyz, vc, fov_cfg, pitch_rad=pitch_rad)
    # vertical: integrate a_up into a v_up setpoint (NED: v_down_extra = -v_up).
    # CLAMP with a DEDICATED FOV_VERT_MAX, *not* V_VERT_MAX=0.5 m/s (review
    # finding 2). V_VERT_MAX is the altitude-hold TRIM limit; at 0.5 m/s the
    # barrier physically cannot re-center a 0.45 rad offset inside ~1.6 s
    # (the module's own closed-loop test needs ~1 m of climb) -> a gutted
    # lever and a false-negative A/B. Size FOV_VERT_MAX from the vertical
    # authority budget (a_up_max * a settling time), e.g. ~2-3 m/s.
    v_up = _clamp(v_up + fov.a_up_m_s2 * dt, -FOV_VERT_MAX, FOV_VERT_MAX)
    # v_down currently comes from the altitude-hold KP_ALT block (~line 3403);
    # under --fov-hold ADD -v_up to it (FOV-hold owns the vertical channel in
    # the terminal, altitude-hold becomes the trim). Log fov.eps_v_rad,
    # fov.barrier_active, fov.a_fwd_cap_m_s2 to new CSV columns.
    # a_fwd_cap: min() it into the dash/closing-speed planner's own accel cap.
```
- `pitch_rad` uses `state.pitch_deg`, which m4 ALREADY maintains (m4:1372,
  read ~line 2470) — no need to re-derive Euler from the quaternion.
- Get `fy`,`height` from `get_camera_intrinsics(...)` (already called ~line 4055).
- Add `--fov-vert-max` (default e.g. 2.5) so the vertical authority is a
  tunable A/B knob, not a magic constant.
- **A/B:** wedge-only PN vs `--fov-hold`; metric = **fraction-of-ticks
  target-in-frame across 8–12 m** (vs measured ~75% out) + miss. Paired seeds
  n≥8 (statistics-before-verdicts rule).

**Real-lens note:** in sim, `meas.meas_xyz` is already an ideal-pinhole ray.
On the hardware wide M12 lens, feed the **undistorted** ray
(`flight.camera.CameraModel.pixel_to_ray(u,v)`) as `meas_xyz`, or use
`pixel_v_to_look_angle` on the undistorted `v` — not the raw distorted pixel.

---

## Phase C — `flight/range_fusion.py` behind `--range-fusion`

**What it is.** `R = fx·W/w_px` from the detector bbox width (`W≈0.3 m` known),
run through a width-channel α-β/Kalata filter so range, closing rate
(`Rdot=−fx·W·ẇ/w²`) and **τ=w/ẇ** fall out **without differentiating range**.
Folded into the *existing* range filter as a **coarse prior** through the
filter's audited `correct(meas,t,gain_scale=w)` port — the same inverse-variance
mechanization `FusedTrack.update_cue` uses for the cue range. **Honest noise:**
`σ_R/R = σ_w/w` RSS'd with a bank-foreshorten fraction — a ±1 px error on a few-px
box is ~10–30% range error, hence *prior, never primary*.

**Wire-up in `m4_intercept.py`:**
```python
# construct once alongside range_filter (~line 2187):
if args.range_fusion:
    from flight.range_fusion import SizeRangeEstimator
    size_est = SizeRangeEstimator(fx)          # W defaults to 0.30 m

# every control tick, mirror the range_filter.predict cadence (~line 2480):
if args.range_fusion:
    size_est.predict(dt)

# feed the WIDTH channel only on a fresh detection with a bbox width
# (in the `if fresh:` block, alongside range_filter.correct ~line 2607):
if args.range_fusion and fresh and box_w_px is not None:
    size_est.correct(box_w_px, tick_start)     # SIM time

# fuse EVERY ENGAGE tick (NOT only in the fresh block) -- review finding 1.
# fuse_into's min_dt_s guard makes it a NO-OP on the tick the camera just
# corrected range_filter (folding a coarse prior at the SAME sim time would
# collapse dt_since to 1e-3 and inject tens of m/s of Rdot into the DEFAULT
# fixed-gain range filter -> vc=-Rdot -> a_cmd blows up). The prior's value
# is exactly the COASTING ticks (sparse in-flight detection), which the guard
# lets through:
if args.range_fusion and phase == "ENGAGE":
    size_est.fuse_into(range_filter, tick_start)   # coarse prior, gain-scaled + dt-guarded
```
- **`box_w_px` is the missing input on the AprilTag baseline.** The `Measurement`
  dataclass (`m3_static_intercept.py:189`) carries no bbox width today. Either
  (a) add a defaulted `box_w_px: Optional[float] = None` field (defaulted →
  every existing 6-positional construction stays byte-identical, exactly how
  `source` was added, ADR-0058), populated by the markerless detector
  (`nn_seeker.py` has `box_xywh`, line ~117) and by an AprilTag corner-span for
  the tag baseline; or (b) pass the detector box straight through. This is the
  one small non-`flight/` edit Phase C needs — flagged so it is visible.
- `SizeRangeEstimator.tau_s` is **also the Phase D arm signal** — expose it.
- **Disclose in the A/B writeup (review finding 6):** the prior shares the
  ONE range α-β filter, so each fused correction shortens `dt_since` for the
  *next* camera correction (the β/dt term) — it subtly rewires the primary's
  rate response even at small weight. This is intrinsic to composing one
  filter and is the SAME accepted property as the cue-range `update_cue`
  precedent (m4:1214-1218); `fusion_weight` mirrors that mechanization exactly.
- **A/B (guidance_lab first, then Gazebo):** size-R prior vs geometry-only, with
  W-foreshortening injected as noise; metric = miss + t_go error.

---

## Phase D — `flight/terminal_coast.py` behind `--terminal-coast`

**What it is.** On a FOV-edge/track-loss flag **inside the τ-armed endgame**,
freeze the last-good LOS-rate + Vc and propagate the PN command open-loop on the
own-state EKF for the measured ~0.1–0.2 s blind window. Terminal LOS is
485–1870°/s, so a stale *command/angle* diverges within a frame — freezing the
**rate** and continuing to integrate the constant `N·Vc·λ̇` holds the commanded
ZEM correction through impact. **Armed by τ (time-to-contact from bbox growth),
never wall-clock**; duration bounded by `max_coast_s` of **sim** time.

**Name-collision warning (do not conflate):**
- `--terminal-coast-gate` (existing) = a **phantom-rejection range gate**
  (ADR-0057). Unrelated.
- The existing inline "terminal coast" (`frozen_vworld` at
  `TERMINAL_FREEZE_RANGE_M=2.0`, m4:3392-3401) freezes the **velocity vector**
  on a RANGE trigger (r_hat < 2 m, live track) and drops further correction.
  **That block IS the Phase D A/B baseline** — this module is the
  freeze-*and-propagate* alternative, triggered on **track loss**. A/B = the
  two against each other on the same flights, compare CPA.

**IMPORTANT — the two must be mutually exclusive (review finding 3).** The
existing `frozen_vworld` block triggers on range and this module triggers on
loss, so both can fire in sequence (freeze the velocity at 2 m, then a loss
un-freezes it as this coast takes over) — an incoherent hybrid that measures
neither arm. So **`--terminal-coast` MUST bypass the `frozen_vworld` block**
(guard it `if frozen_vworld is None and not args.terminal_coast:`), making the
A/B a clean either/or. Log which arm produced each terminal command.

**Wire-up in `m4_intercept.py`:**
```python
# construct at ENGAGE start:
if args.terminal_coast:
    from flight.terminal_coast import TerminalCoast
    coast = TerminalCoast(n_gain=N_PRONAV)     # arm_tau_s/max_coast_s/tau_stale_s tunable

# every ENGAGE tick WITH a live track (after λ/R filters + size_est update):
if args.terminal_coast:
    coast.update_track(lambda_hat, lambda_dot_hat, vc, tick_start,
                       r_hat_m=r_hat, tau_s=(size_est.tau_s if args.range_fusion else None))

# on a track-loss tick (INSTEAD of the frozen_vworld branch, which is bypassed):
if args.terminal_coast and coast.on_track_loss(tick_start):
    cc = coast.command(tick_start)
    if not cc.expired:
        u = (math.cos(cc.lambda_rad), math.sin(cc.lambda_rad))
        p = (-u[1], u[0])
        v_perp = _clamp(v_perp + cc.a_lat_m_s2 * dt, -V_PERP_MAX, V_PERP_MAX)
        # Along-LOS speed: keep the LIVE commanded closing speed (a COMMANDED
        # constant, not a sensed quantity that dies with the camera) so the
        # coast tests ONLY the freeze-the-LOS-rate concept, with no unrelated
        # closing-speed STEP at coast entry (review finding 3). cc.vc_m_s is
        # the frozen -Rdot estimate; use it for the frozen a_lat above, not
        # for the along-LOS term.
        v_close_coast = compute_v_close(cc.r_m if cc.r_m is not None else r_hat, coast_fpv)
        vh0 = v_close_coast * u[0] + v_perp * p[0]
        vh1 = v_close_coast * u[1] + v_perp * p[1]
    # else: expired -> fall through to existing hold/breakoff policy.
```
- **τ dependency:** `--terminal-coast` is only *armable* when it gets a τ. With
  `--range-fusion` off (no bbox stream) `tau_s=None` → the coast **never arms**
  and is inert (safe default). So the natural A/B order is C then D, or D as a
  refinement of the existing `frozen_vworld` block using its own range-derived τ.
- **τ is STICKY (review finding 4):** a single noisy `wdot` dip → `tau_s=None`
  on the final live tick does NOT disarm — the last valid τ keeps the arm alive
  for `tau_stale_s` (0.30 s default), long enough to cover the loss-detection
  gap, then goes stale so an old opening geometry can't hold it armed.
- Coast is a **sim-time** window (`max_coast_s`, default 0.25 s > measured
  0.1–0.2 s); an RTF sag cannot stretch it (ADR-0009).
- **A/B:** on flights with a real terminal track, freeze-and-propagate (this) vs
  hold-last-command (`frozen_vworld`); metric = **CPA** (the ram bar, 0.35 m, ADR-0084
  contact, not the 2.5 m Pk proxy).

---

## Test + gate

```
.venv/bin/python -m pytest flight/tests/test_fov_guidance.py \
    flight/tests/test_range_fusion.py flight/tests/test_terminal_coast.py -q
# 32 passed
```
Also runnable standalone (exit 0/1) like the other `flight/tests/`:
`.venv/bin/python flight/tests/test_fov_guidance.py`. They join the main offline
suite automatically (`scripts/run_tests.sh` globs `flight/tests/`). All math is
pure Python — **no sim, no Gazebo** — exercising each lever on synthetic inputs:
size-range recovers a known R, τ counts down ~1 s/s, the FOV term reduces a
pixel offset and holds the target in-FOV over a closing run, and the coast
propagation matches a constant-velocity LOS.

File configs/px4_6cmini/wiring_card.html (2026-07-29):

Bench card · brn-02 / brn-03 · 2026-07-27

# Three wires to the Pi, and one GPS that lives on the wrong port

Everything below is the Pixhawk 6C Mini talking to the Raspberry Pi 5 over one serial line. Nothing here can spin a motor — there is no airframe and no ESC.

## First The cable, because DuPont does not fit

You were right to stop. TELEM2 is a JST-GH 1.25 mm 6-pin socket — the same tiny latching type as your GPS plug. A DuPont jumper cannot go into it; the pitch is less than half as wide. The repo said "three DuPont jumpers," which described the Pi end only. That wording has been corrected.

What you need at the flight-controller end is one of:

A JST-GH 6-pin to DuPont-female cable — sold as a Pixhawk telemetry-to-DuPont lead. Plugs into TELEM2, the loose ends push onto the Pi header.

✓

best

A spare Holybro 6-pin telemetry cable with DuPont females crimped or soldered onto three of its wires.

✓

works

Forcing DuPont pins into the JST-GH socket, or using the MAIN / AUX headers because they accept jumpers.

✕

no

MAIN and AUX are not serial ports

Those 3-pin S / + / − headers are the PWM motor outputs. They carry a servo signal and a 5 V rail. Wiring the Pi's GPIO to them puts 5 V on a 3.3 V pin and connects nothing useful.

Four ports look identical

POWER1, TELEM1, TELEM2 and GPS2 are all 6-pin JST-GH. They are distinguished only by the silkscreen label next to the socket. Read it before it clicks in — POWER1 carries the battery sense rail.

## brn-03 TELEM2 → Pi 5

What the six pins on TELEM2 actually are, with pin 1 identified by the red wire:

1VCC +5Vleave off

2TX (out)use

3RX (in)use

4CTSunused

5RTSunused

6GNDuse

Pins 4 and 5 are hardware flow control, deliberately unused — MAV_1_FLOW_CTRL = 0 in bench.params turns it off so the floating CTS line can't stall the link.

6C Mini TELEM2

Pi 5 header

pin 2 — talksTX (out)

→

pin 10 — listensGPIO15 / RXD

pin 3 — listensRX (in)

→

pin 8 — talksGPIO14 / TXD

pin 6GND

→

pin 6GND

pin 1 — red wire+5 V

✕

nowherewould feed 5 V into a 3.3 V GPIO

A talk pin always goes to a listen pin — that is all "TX/RX crossed" means. Both sides are 3.3 V logic, so no level shifter. Ground is the third wire and it is not optional: without a shared ground the other two carry nothing meaningful.

odd row
(inner)

1

3

5

7

9

11

13

15

17

19

21

23

25

27

29

31

33

35

37

39

even row
(board edge)

2

4

6

8

10

12

14

16

18

20

22

24

26

28

30

32

34

36

38

40

6 = GND · 8 = TXD · 10 = RXD all three are adjacent, on the outer row, near the pin-1 end

Confirm the orientation on your own board

Don't trust a drawing for which end is pin 1. Run pinout on the Pi — it ships with Pi OS and prints your actual board with the header mapped, so you can match it to what's in front of you before anything is pushed on.

## 5a Splicing a TELEM↔TELEM cable

Cutting a spare 6-pin TELEM cable and soldering Dupont pigtails onto three of its wires is a normal move. Two things make it worth doing carefully: five of the six wires are usually the same colour, and the colour convention is vendor discretion, not standard — one distributor warns in writing that the red wire may not be pin 1. So every identification here is measured, not counted, and the order below matters.

Check the mail before the scissors

A ready-made JST-GH → Dupont pigtail is already on order. Cutting pins 4 and 5 off a TELEM cable is permanent, so this donor can never carry a SiK radio afterwards. Hand-make one only to close the link tonight.

1. Find GND with the meter, not the colours. FC unpowered, USB out, cable plugged into TELEM2. Continuity mode: one probe on the FC's USB shell, touch each wire at the far plug. The one that beeps is pin 6. Flag it within 10 mm of the plug boot.
  Pin order is only guaranteed at the boot. Probe the wires, never inside the 1.25 mm socket — a probe tip in there bridges pins.
2. Find +5 V. Power the FC on USB only. DC volts, black probe on your flagged GND. The wire reading ≈5 V is pin 1. Flag it.
  If NOTHING reads 5 V, that is a legitimate result, not a mistake — the peripheral 5 V is a switched, current-limited rail and USB-only behaviour is undocumented for this board. Fall back to: pin 1 is the wire at the opposite ribbon edge from measured GND. Do not re-cut.
3. Count inward from both measured ends. From pin 1: next is 2 = TX, then 3 = RX. From pin 6: next in is 5 = RTS, then 4 = CTS.
  Counting from an edge is flip-invariant — turning the cable over never reverses the sequence. Anchoring from opposite ends is what separates TX (pin 2) from RTS (pin 5): both are FC outputs and both read a clean logic level, so voltage alone cannot tell them apart.
4. Cut. Then solder — heatshrink threaded on FIRST. It will not go on afterwards; the Dupont housing is too fat. Lap the strands side by side, one joint at a time, three different jumper colours.
  Only now is it safe to cut, because both anchors are already measured and flagged.
5. Cap the three you don't use — +5 V, CTS, RTS — back to ~10 mm, each in its own heatshrink.
  Short leaves nothing to flop onto the Pi header. Pin 4 is an FC input, and TELEM pins are not documented as 5 V tolerant.
6. Continuity sweep, unplugged and unpowered — all 15 pairs, capped stubs included.
  +5 V against TX, RX or GND is the pair that kills a GPIO or crowbars the FC rail. Continuity means nothing while the plug sits in a powered board.
7. Wire to the Pi with everything dead. GND first, then RX, then TX. Remove GND last when dismantling.
  Pi header pin 6 (GND) is one pin from pin 4 (+5 V) — a one-pin slip dumps the Pi's 5 V into the FC's ground. And until GND is joined, two independently powered grounds float relative to each other.
8. Prove it in two stages. GND + FC TX only → byte check. Then power down, add FC RX → MAVSDK check.
  Stage one involves no Pi output, so a wrong guess costs nothing. Bytes arriving is the only thing that actually proves a serial lead.

## brn-02 The M10 on GPS2

No wiring for this one — the plug goes straight in. GPS2 is 6-pin JST-GH carrying a UART and an I²C bus, which is why a GPS-plus-compass module fits a single socket:

1VCC +5Vpower

2TX (out)gps

3RX (in)gps

4SCLi²c bus 2

5SDAi²c bus 2

6GNDground

Set GPS_1_CONFIG to "GPS 2" and SER_GPS2_BAUD to Auto, then reboot. Use GPS_1_CONFIG, not GPS_2_CONFIG — the latter leaves the primary GPS pointed at an empty port, failing forever.

The compass will not appear, and that is not a fault

PX4 v1.16 on this board starts the external magnetometer on I²C bus 1 (GPS1's) and bus 4 (internal) only. GPS2's I²C is bus 2, which is never scanned — so the M10's compass is invisible, looking exactly like a dead module. The bench uses the board's internal compass instead; a 6→10-pin cable moves the module to the scanned bus for flight. Full reasoning in ADR-0091.

## Checks, in order — stop at the first failure

1. In QGC's MAVLink Console (Analyze Tools), run gps status.

# also useful, prints the live values:
listener sensor_gps

  Proves the driver found the receiver and identified its protocol. Indoors you will see few or zero satellites — that is the roof, not a wiring fault. A named device and a u-blox protocol line is the pass here; the satellite count is what you check outdoors.
2. Free the Pi's serial port: sudo raspi-config → Interface Options → Serial Port → login shell No, serial hardware Yes. Reboot.

ls -l /dev/serial0        # should point at ttyAMA0
grep -o 'console=serial0' /boot/firmware/cmdline.txt   # must print NOTHING
  By default Linux runs a login prompt on those pins and eats every MAVLink byte before your code sees it.
3. Raw bytes on the wire.

stty -F /dev/ttyAMA0 921600 && timeout 3 cat /dev/ttyAMA0 | xxd | head
  Hex scrolling proves the FC → Pi direction only. Silence means: wrong device, TX/RX not crossed, console still holding the port, or a baud mismatch.
4. MAVSDK parses a heartbeat — this closes brn-04.

.venv-seeker/bin/python -c "import asyncio; from mavsdk import System
async def m():
    d=System(); await d.connect(system_address='serial:///dev/ttyAMA0:921600')
    async for s in d.core.connection_state():
        print('connected', s.is_connected); break
asyncio.run(m())"
  Bytes are not just present but well-formed MAVLink. Still only one direction.
5. The gate — this closes brn-05, the one link the simulation never exercised.

scripts/check_deploy_bench.sh
  Connect → own-state → OFFBOARD accepted → a measured setpoint stream → clean stop, all disarmed. The advancing own-state stamp is the only evidence bytes went back up the wire, so this is where your Pi → FC lead is proven. It refuses to pass over USB and exits 3 instead.

If it connects but stalls in half-second chunks

That is hardware flow control on a three-wire link. Confirm MAV_1_FLOW_CTRL = 0 actually took, in QGC's Parameters page. The rest of the failure ladder, in likelihood order, is in configs/px4_6cmini/README.md.

Sources: Holybro Pixhawk 6C Mini port pinout · PX4 v1.16 serial-port configuration · PX4 v1.16 boards/px4/fmu-v6c/init/rc.board_sensors

Project: configs/px4_6cmini/README.md · ADR-0091 · docs/project_state.json → build_tab → brain

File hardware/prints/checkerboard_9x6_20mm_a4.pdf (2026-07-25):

# Camera calibration checkerboard -- 9 x 6 INNER CORNERS, 20.0 mm squares

board 200.0 x 140.0 mm (10 x 7 squares) | inner-corner span 160.0 x 100.0 mm | page 2 is the board
1. PRINT SETTINGS. Scale 100% / 'Actual size'. NEVER 'fit to page' or 'shrink oversized pages'. Landscape. Duplex OFF. MATTE plain paper -- gloss reflects the light you are calibrating under.
2. VERIFY THE PRINTER on the bars below BEFORE you mount the board.
200.0 mm bar and 150.0 mm bar, measured with a steel rule. Out by >1 mm -> fix the dialog and reprint.
3. MOUNT IT DEAD FLAT. Spray-mount page 2 to foamboard, MDF, or glass -- no bubbles, no bow, no curl. After scale, FLATNESS is the dominant calibration error: a 2 mm bow across the board biases the
distortion coefficients and the RMS will still look fine. Tape at the corners only is NOT enough.
4. MEASURE THE BOARD ITSELF (the board is its own ruler -- do this even if you bought a board). Outermost inner corner to outermost inner corner: 160.0 mm along the LONG axis, 100.0 mm along the short axis. Full black extent: 200.0 x 140.0 mm. Divide the long span by 8 to get your ACTUAL square size
and pass THAT to --square. Do not assume the nominal value.
5. CAPTURE >= 15 views (build_tab skr-06 acceptance: RMS reprojection <= 1.0 px). Vary angle, distance and position; fill the corners of the frame, not just the centre; keep the board sharp (it is the LENS you are measuring, not the paper). Shoot in the FINAL tripod geometry, and re-shoot a short set at end of session to catch thermal drift (tripod_test_protocol.md 5).

### 6. RUN:

scripts/calibrate_camera.py --images 'calib/*.png' --cols 9 --rows 6 --square 0.020 --out calib.json

Every range and bearing the campaign produces is wrong until this passes. A uniform print-scale error
is INVISIBLE in the RMS -- it is consistent with itself. The bars in step 2 and the measurement in
step 4 are the only things standing between a 3% print error and a 3% error in every number.
0 | 50 | 100 | 150 | 200

THIS BAR MUST MEASURE EXACTLY 200.0 mm

0 | 50 | 100 | 150

THIS BAR MUST MEASURE EXACTLY 150.0 mm

0 | 50 | 100 | 150 | 200

SCALE CHECK: exactly 200.0 mm

9 x 6 inner corners, 20.0 mm squares -- print at 100% / actual size

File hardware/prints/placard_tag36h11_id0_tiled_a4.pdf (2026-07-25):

# AprilTag placard -- tag36h11 id 0 -- TILED HOME PRINT

Black square (= pupil-apriltags tag_size) = 350.0 mm | cell = 43.75 mm | sheet = 450 x 450 mm | 3 x 2 = 6 tiles
1. PRINT SETTINGS -- get these wrong and every range the campaign measures is wrong.
Scale: 100% / 'Actual size'. NEVER 'Fit to page', 'Shrink oversized pages' or 'Scale to fit'.
Orientation portrait. Duplex OFF. Paper: A4 210 x 297 mm.
Toner/laser on plain MATTE bond. No gloss, no lamination -- specular sun glare kills the decode (docs/placard_mount.md 2; Gazebo has no glare model so no sim result covers it).
2. VERIFY THE PRINTER before cutting anything: measure the two bars below with a steel rule.
Vertical bar = 200.0 mm. Horizontal bar = 150.0 mm. Off by more than 1 mm -> fix the print dialog, do not proceed.
3. ASSEMBLE. Tiles are labelled C<col>R<row>, row 1 = TOP. Each tile overlaps its neighbours by 10 mm.
a) Lay out the grid face up in the C/R order printed in each header.
b) Trim the RIGHT and BOTTOM white edge off every tile except the last column / last row,
cutting on the dashed 'NEXT TILE STARTS HERE' line.
c) Slide each trimmed tile onto its neighbour until the TAG ARTWORK lines up across the seam --the black cell edges are the registration, and they are a finer cue than any printed mark.
d) Tape the seams on the BACK. Any tape on the front adds gloss -> glare.
e) Trim the assembled sheet on the dashed 450 mm trim line / corner crop marks.
4. ACCEPTANCE CHECK (do not skip -- this is the one that catches a bad assembly).
Measure the BLACK SQUARE edge, both axes: 350.0 +/- 1.0 mm. Measure both diagonals: equal within 2 mm. Then measure the white sheet: 450 x 450 mm. If the black square is right but the sheet is not, re-trim;
if the BLACK SQUARE is wrong, the print scaled -- reprint. The quiet zone (50 mm of white all round)
must be clean: no tape, no pen marks, no crop marks inside the sheet.
5. PRINT TWO of these -- one per panel face, both RIGHT-READING. Do NOT photocopy one and flip it: a mirrored tag36h11 is not a member of the family and will simply never decode (placard_mount.md 3.6).

0

50

100

150

200

THIS BAR MUST MEASURE EXACTLY 200.0 mm

0 | 50 | 100 | 150

THIS BAR MUST MEASURE EXACTLY 150.0 mm

tile map (as taped up)

C1R1

C1R2

C2R1

C2R2

C3R1

C3R2

PLACARD tag36h11 id 0 | TILE C1R1 of 3x2 | PRINT AT 100% / ACTUAL SIZE -- NO fit-to-page

<-- SCALE CHECK: this bar = EXACTLY 100.0 mm

TRIM: next tile (C2) starts here -->

TRIM: next tile (R2) starts here

PLACARD tag36h11 id 0 | TILE C2R1 of 3x2 | PRINT AT 100% / ACTUAL SIZE -- NO fit-to-page

TRIM: next tile (C3) starts here -->

PLACARD tag36h11 id 0 | TILE C3R1 of 3x2 | PRINT AT 100% / ACTUAL SIZE -- NO fit-to-page

PLACARD tag36h11 id 0 | TILE C1R2 of 3x2 | PRINT AT 100% / ACTUAL SIZE -- NO fit-to-page

TRIM: next tile (C2) starts here -->

PLACARD tag36h11 id 0 | TILE C2R2 of 3x2 | PRINT AT 100% / ACTUAL SIZE -- NO fit-to-page

TRIM: next tile (C3) starts here -->

PLACARD tag36h11 id 0 | TILE C3R2 of 3x2 | PRINT AT 100% / ACTUAL SIZE -- NO fit-to-page

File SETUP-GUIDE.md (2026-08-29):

# How to use your Interceptor Sim (plain-English guide)

Everything is installed. You just use the launcher.

## Every time: one click
Double-click **"Launch Interceptor Sim (WSL)"** on your Desktop.
- It opens a terminal straight into your Linux environment (WSL) and starts Claude Code in the project.
- Normal terminal window - copy/paste works (Ctrl+Shift+V to paste).
- Your **RTX 4070 GPU** is available inside it.

## The very first time only (about a minute)
Claude Code walks you through it:
1. Pick a color theme - press **Enter** for the default.
2. Type **/login** - open the link, sign in, and paste the code back.
3. Type **/model** and pick **Fable 5**. (Helper subagents auto-use Sonnet 5.)
4. Type **/go** and press **Enter**. That runs your whole kickoff.

After that, the launcher drops you **straight back into your session**.

## What is in the project
In WSL at `~/interceptor-sim` (Windows mirror in your Downloads > Simulation Work > interceptor-sim folder):
- **docs/goals.md** - what you are building and why.
- **CLAUDE.md** - the session operating notes (build/test, honesty boundary, update ritual); the full operating model is in **.claude/ops.md**.
- **.claude/KICKOFF-PROMPT.md** - the full kickoff (the /go command runs this).
- **.claude/skills/** - px4-gazebo, pronav, sim-milestone, sim-debug, mc-batch (used automatically). Built-in /code-review and /debug too.
- **.claude/agents/** - the Sonnet worker, decision council, and verifier.

## Handy things to know
- **Reopen / resume:** re-run the launcher.
- **GPU:** run `nvidia-smi` in the terminal to see your RTX 4070. Gazebo can use it; batch runs still go headless for speed.
- If a Gazebo window will not render, that is WSL OpenGL being finicky - Claude falls back to headless.

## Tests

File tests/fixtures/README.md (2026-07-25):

# tests/fixtures — the small TRACKED fixtures the offline suite needs on a clean clone

Everything under `logs/`, `scripts/seeker/data/` and `scripts/seeker/weights/` is
gitignored (evidence + 18.5 GB of media/weights, see `docs/license_notice_weights.md`).
Tests that reached into those paths therefore passed on this machine and **errored on
every clean clone** — which is what kept GitHub Actions red on 73/73 runs from the
first push (2026-07-21) until 2026-07-25. This directory holds the minimum tracked
data that makes the offline suite reproducible from `git clone` alone.

## `rig_capture_min/` — 200 KB (fallback for `tests/test_ground_station.py`)

A trimmed copy of `logs/rig_captures/full_sweep_20260709T015530Z/` (the T16 ground
stereo-rig sweep, 3.1 MB / 56 stereo pairs):

| file | why it is here |
|---|---|
| `capture_meta.json` | `RigConfig.from_capture_meta` — baseline, intrinsics, true pose |
| `index.csv` | `load_capture` — per-frame `seq` / `t_sim_nominal` / gt target rows |
| `centroids.csv`, `centroid_cache_meta.json` | ADR-0051 centroid-cache replay cases |
| `left/0000{5,6,7}.png`, `right/0000{5,6,7}.png` | the only real frames a non-onnx case **stats** (`test_datum_bias_shifts_triangulated_position_through_process_frame`; pixels are never opened — centroids are synthesized) |

`tests/test_ground_station.py` prefers the real on-disk capture when present and falls
back here otherwise, so a local run still exercises the full 56-frame sweep. The two
`onnxruntime`-gated cases need frames this subset does not carry (seq 10-15); they
`importorskip` first, and if they are ever reached without the full capture they
**fail loudly** rather than skip.

## `apriltag_sim_frames/` — 772 KB / 32 frames (no-hardware fixture for the field pack)

`scripts/field/01_camera_live_check.sh` defaults its NO-HARDWARE replay to
`scripts/seeker/data/autolabel_sim_20260721T032324Z/images`, and its comment claimed
those frames were "shipped with the repo". They are not — `scripts/seeker/data/` is
gitignored — so on a clean clone the script exited 2 (USAGE: replay dir not found),
`02_apriltag_desk_check.sh` fell through to the same missing path, and
`scripts/field/selftest.sh` reported 2 failures. That is the **third** independent
cause of the 73/73 red CI streak, and it lives in CI stage 4.

This is a 32-frame subset of that same sim capture, sampled evenly across it
(ranges 1.9 m → 29.9 m, 1280×960, each really containing a `tag36h11` at the sim
tag's 0.5 m edge). Both scripts prefer the full 252-frame set when it is on disk and
fall back here otherwise. 32 clears `01`'s default `--frames 30`.

## `field_selftest_frame.png` — 28 KB (fixture for `scripts/field/selftest.sh`)

`scripts/field/selftest.sh` check 5c replays a one-image directory through
`01_camera_live_check.sh --replay --frames 30` to prove a short session FAILS. It
looked for any `*.png` under `scripts/seeker/data/` — a gitignored dataset dir — so on
a clean clone the check reported `no fixture PNG ... cannot test the short-session
branch` and the pack exited 1. This is the SECOND cause that kept CI red: it is
venv-independent and sits in CI stage 4, which was added 2026-07-25 to close the
review-2 "green != ran" finding. One tracked frame (the seq-5 left image from the
same rig capture) makes the check run everywhere.

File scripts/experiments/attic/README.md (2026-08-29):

# scripts/experiments/attic/ — retired one-off tooling

One-off experiment / plot / probe scripts that outlived their analysis. Moved here
2026-07-25 (`git mv`, history preserved — `git log --follow scripts/experiments/attic/<file>`)
rather than deleted, so the analyses stay reproducible.

**Why:** each of these had ZERO references from any tracked file. They inflate the
tree a portfolio reviewer reads, and several are named like live verification tooling
(`verify_autocrop.py`, `verify_grid_labels_v3.py`, `phantom_forensics_v3.py`) — the
kind of thing someone re-runs and trusts even though nothing is wired to it, which is
this project's named defect class (CLAUDE.md, "instruments are evidence").

**Nothing here is wired to a gate.** Do not cite output from an attic script as
evidence without re-establishing that it still matches the code it measures.

| script | retired | what it did |
|---|---|---|
| `plot_t21_maneuver.py` | 07-09 | T21 maneuver trajectory plot |
| `wait_batch_string.sh` | 07-09 | batch-completion poller |
| `analyze_v2_ab.py` | 07-08 | seeker v2 A/B analysis |
| `plot_seeker_ab.py` | 07-08 | seeker A/B plot |
| `phantom_forensics_v3.py` | 07-09 | v3 phantom-detection forensics |
| `verify_grid_labels_v3.py` | 07-09 | v3 grid label check |
| `probe_v2.sh` | 07-11 | v2 probe driver |
| `verify_autocrop.py` | 07-12 | foveated auto-crop check (ADR-0074) |
| `prop_mask.py` | 07-20 | propeller-mask experiment |
| `onnx_smoke_test_aug.py` | 07-21 | nn_tier augmented-model ONNX smoke test |

## Deliberately NOT attic'd

The 2026-07-25 audit listed 12 orphans. Re-verification before the move
(scan corpus = ALL 626 tracked text files, not just `docs/ tests/ flight/ scripts/
.github/`) found **two of the twelve are still referenced**, so they stayed put:

- `scripts/bird_mc_harness.py` — cited by `models/fpv_bird_decoy/model.sdf:5,62` and
  `models/fpv_bird_decoy/model.config:12` as the harness those assets exist for.
- `scripts/gen_demo_ground_texture.py` — cited by `worlds/apriltag_demo.sdf:177`
  ("the generator, keep its ...") and `demo_out/README.md:148`.

Moving either would break a provenance pointer inside a committed world/model asset.
The audit's orphan scan simply did not read `models/`, `worlds/` or `demo_out/`.

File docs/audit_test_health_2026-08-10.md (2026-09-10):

# Test-suite health audit — 2026-08-10

Independent read-only audit of the offline test suite, run overnight. Recorded here
because the findings would otherwise have existed only in an agent transcript — which
is the same single-copy failure the skr-07 evidence rescue fixed the same day.

**Scope:** offline suite only. No Gazebo, no PX4, no Monte-Carlo — the sim is serialized
and the builder was asleep.

---

## Headline

The suite is **substantially healthy and unusually well designed**: 739 passing tests,
deterministic across repeated runs, ~35 s end to end, **zero** `assert True`, zero
vacuously-true `all()`/`any()` assertions, a real producer-written-fixture contract-test
culture, working `--self-test` gating with a coverage-drift guard, and a model-blocking
hook that does exactly what its docs claim.

**The problem was never in the assertions. It was in the reporting layer around them.**

---

## What was found, and what was done

| # | Finding | Severity | Status |
|---|---|---|---|
| F1 | `run_tests.sh` RED at HEAD for 12 days / 9 commits | **CRITICAL** | ✅ FIXED |
| F2 | Under-powered range calibration consumed as calibrated | **HIGH** | ✅ FIXED |
| F3 | Flight-CSV completeness guard can verify zero units and pass | HIGH | ⬜ OPEN |
| F4 | Corrupt calibration reported identically to a missing one | MEDIUM | ✅ FIXED |
| F5 | `test_camera_fps_pinned` could never run (no `build_argparser`) | MEDIUM | ✅ FIXED |
| F6 | `test_decode_fps_bound_contract` pointed at a never-existent path | MEDIUM | ✅ FIXED |
| F7 | Stage 1 had no skip enforcement (the mechanism that hid F5/F6/F8) | MEDIUM | ✅ FIXED |
| F8 | Three tests pass locally, silently skip in CI (untracked fixture) | LOW/MED | ✅ FIXED 2026-09-10 |

### F1 — the gate was not gating (fixed, `dd0f6d4`)

`flight/tests/test_seeker_loop_coast.py:373` asserted the DEFAULT config accepts a 1.50 s
stale own-state. ADR-0093 (`4df285f`, 2026-07-29) turned that gate ON at 0.25 s.

The instructive part is *how it survived*. ADR-0093's commit message certifies
**"Suite 519 passed."** Measured: 519 is *exactly* `pytest tests/`. The 173-test
`flight/tests/` half — which `run_tests.sh` stage 1 also runs, and where the
contradicting test lives — **was never executed**. The commit certified a suite it had
not run, and nine commits landed on top.

Two tests asserted opposite things about one constant:

- `tests/test_own_state_age_gate.py:46` — default `is not None`
- `flight/tests/test_seeker_loop_coast.py:373` — default accepts a stale sample

The **code was right**; the test was the stale artefact, and its docstring
("the AGE gate is off by default on purpose — no measured own-state stall latency exists
yet") was a claim brn-05 had already falsified on hardware.

### F2 — an unvetted span could steer the aircraft (fixed, `dd0f6d4`)

Seam: `scripts/seeker/calibrate_range.py` (producer) → `flight/deploy/seeker_loop.py:resolve_span`
(consumer). **No contract test existed on this seam at all.**

The producer grades its own fit — `return 0 if n_kept >= 20 else 2` — but writes the
sidecar *before* that return, and the consumer never read `n_kept`. So a 3-sample fit the
producer itself graded a FAILURE arrived indistinguishable from a 57-sample fit and was
consumed as `calibrated=True`.

This is not cosmetic. `span_m_eff` sets `range = fx*span/box_width_px`, and range
multiplies `Vc` into the pro-nav command `a_cmd = N·Vc·λ̇`, as well as keying every
range threshold (closing-speed throttle, terminal freeze, breakoff arm, hard floor).

Fixed on both sides, plus `tests/test_range_calib_contract.py` (8 tests, mutant-verified —
restoring the defect kills 4).

### F3 — the one true vacuous verdict (OPEN)

`tests/test_flight_csv_contract.py:118` calls itself a *"mechanical completeness guard"*.
It regex-sweeps three consumers for row reads and asserts `not unknown` — but **never
asserts the sweep found anything**. Mutant-proven: renaming the row variable `r` → `rec`
(a plausible refactor the regex does not match) drops the swept count from 8 to **0** and
the assertion still passes, having checked nothing.

The repo already knows this shape — the sibling `tests/test_ci_gz_deselect_list.py`
contains a test literally named `test_the_measurement_is_not_vacuous`. Fix is one line per
file: `assert len(reads) >= <floor>`.

### F7 — skip-blindness (fixed, `dd0f6d4`)

Stage 2 failed on any skip; stage 1 — 692 of 721 tests — had no `-rs` and no check. That
asymmetry is precisely what let F5, F6 and F8 sit invisible. Stage 1 now requires every
skip to be declared in `ALLOWED_SKIPS` with a human-written reason. Mutant-verified.

### F8 — CI-only skips (FIXED 2026-09-10)

`tests/test_t18_scaffold.py`'s `rig` fixture needs
`logs/rig_captures/full_sweep_20260709T015530Z/capture_meta.json`, which is **untracked**.
Three of four tests take that fixture, including
`test_sigma_R_scaling_reproduces_analytic_row`. Locally: 4 passed. On a clean clone or in
CI: 3 skip silently. Now *visible* thanks to F7's enforcement, but the fixture still needs
either committing or an explicit allowlist entry.

**CLOSED 2026-09-10, and it was worse than this entry recorded.** Reproducing stage 1's own
gate on a clean clone found **seven** undeclared skips, not three — the T16 capture (×3), the
gz/MAVSDK bindings (×2, `test_wind_wiring` and `flight/tests/test_real_flight`), and the
gitignored deployed weights (×2, `test_deployed_weights`). So `scripts/run_tests.sh` could
not be run **at all** on a fresh checkout: stage 1 printed seven UNDECLARED SKIP failures and
exited 1. None of them fire on the dev machine, where the venv has the bindings and both
artefacts are present, which is exactly why the hole stayed invisible where the runner is
normally used.

Fixed by declaring all seven in `ALLOWED_SKIPS`, each with a written reason and grouped under
a comment saying what is given up: the ability to notice that a clean clone verified less,
which every one of those skip messages already states on its own `-rs` line. The fixture was
**not** committed — it is a multi-GB artefact and the licence policy keeps the weights out of
git regardless.

**The gate keeps its teeth, mutation-verified:** a test file added with a brand-new
undeclared skip reason is still caught and would still fail the stage. The allowlist is
specific substrings, not a wildcard.

*(Contrast, and it is the right pattern: `test_antimirage_pairing.py`'s published-headline
check depends on `logs/mc_loftdive_armA_line9_s123.csv`, which **is** tracked — so it
really runs in CI.)*

---

## Negative results, stated deliberately

A manufactured finding is worse than none, so these are recorded as clean:

- `assert True` / `assert 1` / `assert not False`: **zero** occurrences.
- AST scan for `assert all(<filtered comprehension>)` — vacuous on an empty filter: **0 hits**.
- AST scan for asserts inside loops over possibly-empty iterables: 8 hits, **all cleared**
  (6 iterate module-level constants measured non-empty at runtime; 2 already carry count floors).
- **No flaky tests.** Slowest single test 0.96 s; nothing else above 1 s. No `sleep`, no
  wall-clock reads, no network. Both RNG uses explicitly seeded. Deterministic across
  three full runs.
- **The Opus-4.8 block works as documented.** `tests/test_block_opus48_hook.py`: 40 passed,
  and exercised live — `opus` DENY, `claude-opus-4-8` DENY, `claude-opus-5` ALLOW, no-model
  ALLOW. `.claude/settings.json` wires it on `PreToolUse` matching `Agent|Workflow`.

---

## Uncovered producer→consumer seams (for later)

| Seam | Note |
|---|---|
| `calibrate_range.py` → `resolve_span` | **Was F2. Now covered.** |
| `multirange_capture` → `multirange_nn_detection` → `multirange_sigma_fit` | 3-stage chain producing σ_R (the range noise model). Zero test references. |
| `mc_analyze.py` | An uncovered *consumer* of a covered producer — it is absent from `test_flight_csv_contract.py`'s enumerated consumer list. |
| `tag_decode_cost.py`, `phantom_competition_replay.py`, `pi_fps_soak.py` | No tests; `pi_fps_soak`'s number reaches `tripod_score` via a CLI flag (no file boundary), so lower priority. |

`tests/test_parse_flight_log_contract.py` is the model to copy: it walks the real state
machine with the producer's own writer and mutation-tests added/dropped columns on both sides.

---

## One config observation — for the builder, not a defect

`~/.claude/settings.json` has `"fastMode": true` persisted globally while `"model"` is
`claude-fable-5`. CLAUDE.md §5 sanctions fast mode for *in-person bench sessions on Opus 5*
and says the head should return to Fable when the bench session ends. A globally-persisted
`fastMode` is the "left a bench-tuned session pinned for a design decision" drift that
bullet warns about.

**Not changed** — it is outside the project directory and is the builder's call.

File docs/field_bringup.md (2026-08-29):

# Field bring-up — "the parts arrived, now what?"

This is the plug-it-in-and-go runbook. One command per piece of gear, a clear
PASS/FAIL, and the two things most likely to go wrong with each.

You do not need to remember any of it. Start here:

```bash
cd ~/interceptor-sim
scripts/field/bringup.sh
```

That runs the laptop-side checks in order and prints one summary table.
Run it today with nothing plugged in — it will tell you what is missing instead
of crashing. Run it again each time a box arrives.

---

## 0. What the checks are

| Step | Command | Question it answers |
|---|---|---|
| 00 | `scripts/field/00_detect_devices.sh` | What does my laptop actually see? |
| 05 | `scripts/field/05_pi_link_check.sh` | Can I reach the Pi on the FIELD network — key, IP, clock? |
| 01 | `scripts/field/01_camera_live_check.sh` | Is the camera making good frames? |
| 02 | `scripts/field/02_apriltag_desk_check.sh` | Does the tag decoder see the placard? |
| 03 | `scripts/field/03_fc_bench_check.sh` | Can I talk to the flight controller? |
| 04 | `scripts/field/04_pull_logs.sh` | Get the logs + video off after a flight |
| all | `scripts/field/bringup.sh` | 00 → 05 → 01 → 02 → 03 in one go |
| — | `scripts/field/selftest.sh` | Are the check scripts themselves healthy? (no hardware, exits 0/1) |

Every script prints one of three verdicts:

- **PASS** — checked, all good.
- **FAIL** — the gear is there and something is wrong. Follow the `->` hints.
- **NOT CONNECTED** — that piece is not plugged in yet. Not an error today.

Exit codes, if you ever script around them: `0` pass, `1` fail, `2` bad
arguments, `3` not connected. Add `--require` to any script (or to
`bringup.sh`) to make "not connected" count as a failure — use that on field
day, when everything *is* supposed to be attached.

Every run writes a folder under `logs/field/` with the full text output, a
sample frame, and a small `verdict.json`. Nothing is lost.

---

## 1. The gear map — what plugs where

| Part | Plugs into | How the laptop reaches it |
|---|---|---|
| **Pixhawk 6C Mini** (interceptor brain, runs PX4) | laptop **USB‑C** | a serial port, `/dev/ttyACM0` — **needs the WSL step in §2** |
| **Kakute H7** (target drone, runs ArduPilot) | laptop **USB‑C** | same as above |
| **innomaker OV9281 camera** | the **Raspberry Pi 5**, by ribbon cable | **not the laptop.** The laptop talks to the Pi over Wi‑Fi |
| **Raspberry Pi 5** (seeker rig) | its own USB‑C power | over the network: `ssh pi@<the Pi's IP>` (see §3.0 — `.local` does **not** resolve from WSL2) |
| **microSD log cards** | a card reader in the laptop | a Windows drive under `/mnt/d`, `/mnt/e`, … |

Two things worth saying once, because they cause most of the confusion:

- **The camera cannot plug into your laptop.** It is a *CSI* camera — a ribbon
  cable that only fits the Pi. It will never show up as a camera on the laptop.
  (Source: `docs/camera_paper_check.md` item 5.)
- **A "charge-only" USB‑C cable will do nothing.** The flight controllers need a
  **data** cable. If nothing at all appears when you plug in, try another cable
  before debugging anything else.

---

## 2. The WSL2 USB step (the #1 gotcha)

You run Ubuntu inside Windows (that is what WSL is). **Windows keeps USB devices
to itself.** Until you hand a device over, Ubuntu — and therefore every script in
this repo — cannot see your Pixhawk at all. The tool that hands it over is
**usbipd-win**. Official instructions:
<https://learn.microsoft.com/en-us/windows/wsl/connect-usb>

### One-time install (Windows side)

Open **PowerShell as Administrator** and run:

```powershell
winget install --interactive --exact dorssel.usbipd-win
```

### Every time you plug a flight controller in

1. Keep an Ubuntu/WSL terminal open (this keeps the Linux VM alive).
2. In **PowerShell (Administrator)**, list the devices and find the one you just
   plugged in. Copy its **BUSID** (looks like `4-4`):

   ```powershell
   usbipd list
   ```

3. Share it (first time per device, needs Administrator):

   ```powershell
   usbipd bind --busid 4-4
   ```

4. Attach it to Ubuntu (no Administrator needed):

   ```powershell
   usbipd attach --wsl --busid 4-4
   ```

5. Back in Ubuntu, confirm:

   ```bash
   scripts/field/00_detect_devices.sh
   ```

   You want a line under *Flight-controller serial ports* naming your board.

6. When you are done — or when you want to use **QGroundControl on Windows** —
   give the device back:

   ```powershell
   usbipd detach --busid 4-4
   ```

**Important:** while a device is attached to WSL, **Windows cannot use it**. So
QGroundControl (which you run on Windows to flash firmware and calibrate
sensors) will not find the board until you `detach`. Rule of thumb: *QGC first,
detached; then attach for the Linux scripts.*

Convenience: `usbipd attach --wsl --busid 4-4 --auto-attach` keeps re-attaching
the device on that bus ID if you unplug and replug it. Leave that command
running in its own PowerShell window.

### If the port appears but the scripts say "no permission"

Linux guards serial ports. One-time fix, then close and reopen your WSL
terminal:

```bash
sudo usermod -aG dialout $USER
```

Or, just for this session: `sudo chmod 666 /dev/ttyACM0`.

---

## 3. Raspberry Pi 5 + the OV9281 camera

The Pi is the seeker: it holds the camera and records the frames. It is a small
separate computer, so you set it up once and then reach it over Wi‑Fi.

### 3.0 The networking dry run — DO THIS BEFORE YOU PACK

**This is the most likely way to lose a whole field day with hardware that all
works.** Every capture is *started* by ssh'ing from the laptop to the Pi, and
`04_pull_logs.sh` fetches the session back the same way. At the field the only
network is your phone's hotspot, and three things have to be true that are not true
out of the box:

1. **The Pi has to join the hotspot.** The Pi Imager writes exactly ONE Wi‑Fi
   network — your home one. On site it will look for that, not find it, and never
   appear on the network.
2. **The laptop has to find it.** `interceptor-seeker.local` is *mDNS*, and **mDNS
   does not resolve from WSL2** (your Ubuntu sits behind a NAT with plain
   `files dns` name resolution). Use the **IP**.
3. **ssh has to work without a password.** Every script here uses
   `BatchMode=yes` — a password prompt inside a check script would just hang — so a
   key must exist on the laptop *and* be installed on the Pi.

Do all of it at the desk, in this order:

```bash
# 1. make an ssh key (once, no passphrase -- it lives on your own laptop)
ssh-keygen -t ed25519 -C interceptor-field -N "" -f ~/.ssh/id_ed25519

# 2. turn your PHONE HOTSPOT on, and add it to the Pi as a SECOND Wi-Fi network
#    (do this while the Pi is still on your home Wi-Fi, over ssh):
sudo nmcli connection add type wifi ifname wlan0 con-name field-hotspot \
    ssid '<HOTSPOT SSID>' wifi-sec.key-mgmt wpa-psk wifi-sec.psk '<PASSWORD>'
sudo nmcli connection modify field-hotspot connection.autoconnect yes

# 3. reboot the Pi with the hotspot up, and read the IP it got
#    (on the Pi: `hostname -I`; or look at the phone's hotspot client list)

# 4. install the key on the Pi, then TELL THE SCRIPTS to use the IP
ssh-copy-id pi@192.168.43.17            # <- your Pi's actual hotspot IP
export FIELD_PI_HOST=pi@192.168.43.17   # put this in ~/.bashrc so it always applies

# 5. prove the whole chain, from the laptop, on the hotspot
scripts/field/05_pi_link_check.sh
scripts/field/01_camera_live_check.sh --pi "$FIELD_PI_HOST"
scripts/field/04_pull_logs.sh --pi "$FIELD_PI_HOST" --no-score
```

Step 5 is the point of the whole section: **`01` → `04` must have reached the Pi
from this laptop at least once, over the hotspot, before you drive anywhere.**

`05_pi_link_check.sh` checks the key, the address (and warns about `.local` under
WSL2), that the Pi has the repo + venv + `pi_capture.py` + `rsync`, that its
`sessions/` dir is writable, that there is disk space for a day of PNGs, and the
**laptop↔Pi clock offset** — because the hotspot is also the Pi's only NTP source,
and the frame↔log time join that produces every range number depends on it
(`docs/tripod_test_protocol.md` §6.1). It changes nothing on either machine.

**If it still cannot reach the Pi at the field:**

- Many hotspots have **AP/client isolation** on, which blocks laptop→Pi entirely.
  Turn it off in the phone's hotspot settings (test at the desk!).
- Fallback that always works: **an ssh app on the phone itself** — the hotspot host
  can always reach its own clients. Install one and try it once before the field.
- Pinning the name instead of exporting an IP: `echo '192.168.43.17 interceptor-seeker' | sudo tee -a /etc/hosts`
  inside WSL.

### 3.1 Prepare the microSD card (once)

1. Install **Raspberry Pi Imager** on Windows.
2. Choose **Raspberry Pi OS (64‑bit)**, Bookworm.
3. Open the Imager's **advanced/settings** gear **before** writing and set:
   **hostname `interceptor-seeker`**, a username + password, your **Wi‑Fi**, and
   **enable SSH**. This is what lets you log in with no monitor or keyboard.
4. Write the card, put it in the Pi, fit the **active cooler**, connect the
   camera ribbon (see below), then power the Pi from its own 27 W USB‑C supply.

**Camera ribbon:** the camera board has a **15‑pin** connector; the Pi 5 has a
**22‑pin** one. The included **22→15 adapter cable** is required — the *narrow
22‑pin end goes into the Pi*. Push the latch down until it clicks.

### 3.2 Set the Pi up (once)

From your laptop:

```bash
ssh pi@192.168.1.50        # the Pi's IP; use the username you set in the Imager
                           # (.local works from Windows/macOS, NOT from WSL2 -- see 3.0)
git clone <this repo> ~/interceptor-sim && cd ~/interceptor-sim
bash scripts/pi_setup/provision.sh --dry-run          # shows the plan, changes nothing
sudo bash scripts/pi_setup/provision.sh --hostname interceptor-seeker
sudo reboot
```

Full detail (what it changes and why) is in `scripts/pi_setup/README.md`.

### 3.3 Check the camera — one command, from the laptop

```bash
scripts/field/01_camera_live_check.sh --pi "$FIELD_PI_HOST"   # e.g. pi@192.168.43.17, see 3.0
```

**What a PASS looks like:** `frames: 30`, `resolution: 1280x800`, and
`exposure: applied ~<something ≤1000> us … -> OK`, then `PASS`. Open the saved
`sample_frame.png` it points at and check the picture is sharp and well lit.

Why 1280×800 and why ≤1 ms: that is the sensor's native size, and a very short
exposure is the whole reason we bought a *global shutter* camera — it freezes a
fast-moving target instead of smearing it. The script does not assume the
exposure worked; it reads back what the sensor actually applied.

**Top failure modes**

| Symptom | Fix |
|---|---|
| The command fails on the Pi, or `rpicam-hello --list-cameras` shows nothing | Ribbon is in backwards or not latched, or the overlay is missing. Re-seat the cable (22‑pin end at the Pi), then re-run `provision.sh` (it adds `dtoverlay=ov9281`) and reboot. |
| `exposure … OVER SPEC` or the picture is nearly black | Not enough light for a 1 ms exposure. Do this check in daylight or under a bright lamp, and raise `--gain` if needed. |

**No Pi yet?** Just run `scripts/field/01_camera_live_check.sh`. With no camera
anywhere it replays frames from the repo through the exact same recorder, tells
you the pipeline is healthy, and reports NOT CONNECTED.

Two things it deliberately will *not* do any more (both used to print PASS):

- a **laptop webcam** or the **replay fixture** now reports **NOT CONNECTED**, not
  PASS — neither is evidence the OV9281 works, and `--require` must not be
  satisfiable by them;
- a session that delivers **fewer frames than you asked for** now FAILs (it was
  graded against "at least 1 frame").

### 3.4 Recording an actual pass (not the health check)

`01` is a *health check*. A real tripod/field pass is recorded by running the
recorder on the Pi with the pass sized up front and the calibration + tag size
recorded into the session:

```bash
ssh "$FIELD_PI_HOST" '~/interceptor-sim/.venv-pi/bin/python \
  ~/interceptor-sim/scripts/seeker/pi_capture.py --source picamera2 \
  --out ~/interceptor-sim/sessions/pass01 --duration 20 --exposure-us 1000 \
  --width 1280 --height 800 --calib ~/interceptor-sim/calib.json \
  --tag-size 0.35 --run-tag pass01'
```

The `--calib` / `--tag-size 0.35` pair is what makes the session scorable later;
`docs/tripod_test_protocol.md` §6.0b has the per-pass sanity check to run on the Pi
before flying the next one.

---

## 4. The AprilTag placard check

An **AprilTag** is the black-and-white square marker on the target drone. It is
not a toy: the first real intercepts fly on the *tag*, because the tag decoder
runs fast enough on the Pi's own processor while the neural-net seeker needs the
add-on accelerator we deliberately deferred.

Print the tag first: **tag36h11, id 0, 0.35 m black-square edge** — which is a
**450 × 450 mm physical sheet** (the black square plus the mandatory 1-cell quiet
zone: 0.35 / 0.8 = 437.5 mm, plus margin) — glued to something rigid and flat
(`docs/placard_sizing.md`, `docs/placard_mount.md` §2). The two numbers are not
interchangeable: 0.35 m is what `--tag-size` means (it is what sets the pose), and
0.45 m is what you print and carry.

Then: capture with step 01, and score it:

```bash
scripts/field/01_camera_live_check.sh --pi "$FIELD_PI_HOST"
scripts/field/02_apriltag_desk_check.sh --expect-range 3.0     # 3.0 m tape-measured
```

**What a PASS looks like:** `decoded: 30 (100.0% of frames)`, a tag id, a
`tag in frame: ~NNN px per edge` line, and `PASS`.

#### "Why calibrate at all — can't the loop just steer at the tag?" (builder question, 2026-08-12)

It could, and that is **pursuit guidance** — and pursuit was measured against a
moving target in M4 and lost badly: **2.0–2.5 m** miss versus **0.3–0.4 m** for
pro-nav (docs/progress.md M4). Pro-nav is the law that works, and unlike pursuit it
needs two *quantitative* things a raw image does not provide:

1. **Range.** A single camera's only route to range is apparent size:
   `range = fx · tag_size / width_in_pixels`. Calibration is what measures `fx`
   (focal length in pixels). A wrong `fx` scales **every** range by the same
   factor — and range is not a display value here: it multiplies into the
   acceleration command, and every terminal decision is range-keyed (terminal
   freeze 3.5 m, breakoff arm 4.0 m, hard floor 0.5 m). All of them would fire
   at the wrong true distance. The sim recorded `fx = 539.9` for *its* camera;
   that number is meaningless for any real lens.
2. **Straight lines.** The 118° lens bends the image near the edges. Pro-nav
   steers on the *rate the line of sight rotates*, so through an uncalibrated
   wide lens a target moving in a straight line traces a **curved** pixel path —
   it looks like it is accelerating when it is not, and pro-nav responds to a
   maneuver that never happened. Worst exactly at the frame edges, which is
   where the target sits at handoff.

Tripod day adds a third reason: the money-gate curve converts "tag decoded at N
pixels" into "decoded at X metres", and that conversion **is** the calibration.

Short version: the loop can already *steer* at the tag. Calibration is what lets
it know how far away the tag is and how fast the geometry is really changing —
the difference between the law that lost and the law that works.

About **range**: the tool prints the distance implied by the tag's pose, but it
marks it *INDICATIVE ONLY* until you have calibrated **this** camera. Camera
calibration means measuring the lens's real focal length from photos of a
checkerboard — without it, every distance is wrong by an unknown factor:

```bash
# on the Pi, capture the views (headless, ssh-friendly, reports coverage per shot):
.venv-pi/bin/python scripts/seeker/capture_calib_views.py --out ~/calib_views
# ENTER grabs · s skips · q finishes + verdict. Then solve:
scripts/calibrate_camera.py --images '/home/admin/calib_views/calib_*.png' \
    --cols 9 --rows 6 --square 0.025 --out camera_intrinsics_real.json
```

Once `camera_intrinsics_real.json` exists in the repo root, step 02 picks it up
automatically and starts *grading* range against your tape measure.

#### How far from the board to stand — GET CLOSE (derived 2026-07-31, bench session)

The 118° lens is wide enough that intuition is wrong here by a factor of several,
and the failure is silent: you shoot twenty views, every one of them lands in the
FAR bucket, and `capture_calib_views.py` refuses READY at the end of the session.
Frame width = `2·tan(59°)·d` = **3.33·d**, so a board's share of frame AREA falls
as 1/d². For the checkerboard displayed on a screen
(`hardware/prints/checkerboard_9x6_screen.html`, squares = `min(9.2vw, 12.4vh)`):

| display | board | NEAR (≥25 %) | MID (8–25 %) | FAR (<8 %) |
|---|---|---|---|---|
| 13" laptop 16:9 | 20×14 cm | 13 cm | 13–23 cm | >23 cm |
| 15.6" laptop 16:9 | 24×17 cm | 15 cm | 15–27 cm | >27 cm |
| 24" monitor 16:9 | 37×26 cm | 24 cm | 24–42 cm | >42 cm |
| 27" monitor 16:9 | 42×29 cm | 27 cm | 27–47 cm | >47 cm |

**Use the largest display available.** Not for convenience — for FOCUS. The lens
is ~1.15 mm focal length (118° HFoV across the OV9281's 3.84×2.40 mm sensor), so
with CoC = diag/1500 = 0.0030 mm the hyperfocal distance is **≈22 cm at f/2**
(≈16 cm at f/2.8). A lens focused for FIELD distances is therefore sharp only down
to ~16–22 cm: on a 15.6" laptop the NEAR views sit at 15 cm, *inside* the blur
limit, and come back NOT FOUND. On a 24"+ screen every bucket clears it.

The same number carries the good news: **do not refocus the lens to shoot close.**
Depth of field at this focal length runs from ~20 cm to infinity, and `skr-06`
requires the intrinsics measured with the lens exactly as tripod day will use it —
refocusing between calibration and the field invalidates the calibration.

A printed board is no larger than a laptop screen at these square sizes
(A3 @ 25 mm = 25×17.5 cm), so printing does not solve the distance problem;
only a physically bigger board or a bigger display does.

**Top failure modes**

| Symptom | Fix |
|---|---|
| `only 0 frame(s) decoded` | Get closer, or print a bigger tag; make sure the tag is sharp and in focus (turn the lens ring), evenly lit, not glossy, not curled. |
| Decodes fine but the range is way off | You are using someone else's camera numbers. Run the calibration above. Also check you passed the real printed size with `--tag-size`. |

This is a sanity check, not the real measurement. The proper decode-range curve
— the one that decides whether to order the interceptor airframe — is
`scripts/seeker/tripod_score.py`, run on a tripod session.

---

## 5. Flight controller on the bench (props OFF)

Two boards, same procedure: the **Pixhawk 6C Mini** (interceptor, PX4) and the
**Kakute H7** (target, ArduPilot).

### 5.1 First, on Windows: flash and calibrate

Do this in **QGroundControl** with the board **detached** from WSL (§2):

- **Pixhawk 6C Mini:** *Vehicle Setup → Firmware →* **PX4 Flight Stack (stable)**.
  QGC detects the board as **FMUv6C**. Then *Airframe →* **Generic Quadcopter**,
  Apply & reboot. Put a **microSD** in it — the flight logs are our evidence.
  Step-by-step: `configs/px4_6cmini/README.md`.
- **Kakute H7 (target):** ArduPilot, firmware target **`KakuteH7`** — *not* the
  v2 target. It also needs its own microSD or there is no target log.

### 5.2 Then, in Ubuntu: the link check

```bash
scripts/field/03_fc_bench_check.sh
```

**Props off. This script cannot arm the vehicle** — it only reads. That is not a
promise in a comment: at startup it parses its own source and refuses to run if it
so much as *mentions* a plugin that could command the aircraft — a call, an alias
(`a = drone.action`), an import, or a dynamic `getattr` on the vehicle handle. Six
injected attempts are tested against it in `scripts/field/selftest.sh`.

Scope, stated honestly: that audit covers **this script's own source**, not
everything it could import, and **props off is still the physical interlock.**

**What a PASS looks like:**

```
[fc-link] safety audit OK: ... -- this tool CANNOT arm the vehicle
[fc-link] connected -- heartbeat is alive
[fc-link] armed         : False   <- this tool never changes it
[fc-link] attitude      : roll +0.3 deg  pitch -1.1 deg  yaw +87.0 deg
[fc-link] health readout (read-only):
[fc-link]   OK   gyrometer calibration
...
[03-fc] PASS
```

Tilt the board while it runs — the attitude numbers must move sensibly. That is
your proof the sensors are alive, not just the cable.

`--  global position` will be missing indoors. That is normal: no GPS lock in
the house.

**Top failure modes**

| Symptom | Fix |
|---|---|
| `no serial port found` | The WSL hand-over (§2) has not been done, or the cable is charge-only. |
| `no MAVLink came back` | Something else already owns the port — usually **QGroundControl still open on Windows**. Close it (and `usbipd detach`/`attach` again). Or the board has no firmware yet: flash it in QGC first. |

### 5.3 The next gate after this one

This step proves the *link*. The gate that proves the **autonomy path** —
PX4 accepting streamed guidance commands, still props-off and disarmed — is:

```bash
scripts/check_deploy_bench.sh --check-only     # no hardware: validates the plumbing
scripts/check_deploy_bench.sh                  # the real props-off run
```

Load `configs/px4_6cmini/bench.params` in QGC first, and run it near a window —
that check needs a GPS fix. The pure-software rehearsal of the same code against
the simulator is `scripts/check_deploy_sitl.sh`.

---

## 6. After a flight — collect everything

```bash
scripts/field/04_pull_logs.sh
```

Put both microSD cards in the reader (they appear as Windows drives, so no
usbipd needed) and have the Pi powered on. The script copies:

- the interceptor's PX4 log (`.ulg`) from its card,
- the target's ArduPilot log (`.BIN`) from its card,
- the newest camera session from the Pi,

into one folder under `logs/field/`, and — when both flight logs are present —
runs `scripts/field_score.py`, which computes how close the two aircraft got and
calls KILL or MISS against a lethal radius.

Point it at things explicitly if the auto-scan misses:

```bash
scripts/field/04_pull_logs.sh --px4 /mnt/d --ardupilot /mnt/e \
    --pi "$FIELD_PI_HOST" --session tripod_pass01
```

The **video is still the verdict** (the project's success test is a binary kill
you can see); the score is the number behind it.

**What its verdict means (it changed 2026‑07‑25):**

- **PASS** — every source you asked for came off the aircraft.
- **NOT CONNECTED** — you did not put a card in / the Pi was off. Advisory.
- **FAIL** — a source you *asked for* did not copy, **or** the scorer crashed.
  Either way **everything already copied is safe** in the run folder and nothing
  here ever deletes a source: fix the cause and re-run with the same `--session`.
  **Do not wipe the cards on a FAIL.** (Before this change, a scoring crash printed
  `PASS` and exited 0 — the shape of failure this whole pack exists to prevent.)

The kill/miss threshold is `field_score.py`'s `DEFAULT_LETHAL_RADIUS_M`; read the
mechanism note at that constant rather than any number quoted in a runbook, and
override with `--lethal-radius` (04 forwards it).

**Scoring the tripod session is a different, three-step job** — decode →
`range_truth_join.py` → re-score. Do not point `tripod_score.py` at a session and
expect a verdict: `docs/tripod_test_protocol.md` §7.0 has the exact commands (and
which of the two venvs each one needs).

---

## 7. Order of operations when the boxes land

1. `scripts/field/bringup.sh` on the laptop — proves the software half. (Works
   today, with nothing attached.)
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

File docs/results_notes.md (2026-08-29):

# Results notes — the full scope/caveat text behind the README table

The README's results table keeps every load-bearing scope inline but shortened;
this file holds the complete original caveat prose per row, verbatim, so no
disclosure is ever more than one click from its number. The binding rules for
public wording are in `docs/publish_runbook.md` (claims scrub).

## M0–M2 foundations {#m0m2}

Wide (99.7°) lens; sim lighting. Detection rate and pose error measured against
sim ground truth by the M2 gate (`scripts/check_m2.sh`), 2026-07-04.

## M4 pro-nav vs pursuit {#m4}

Official gate-config runs. **Disclosure (ADR-0009 addendum):** three earlier
dev-phase pro-nav flights that same night read 1.04–1.12 m — over the gate —
before the final configuration; the gate numbers come from the official
gate-config runs and the dev-phase selection is disclosed rather than hidden.

## Two-stage handoff (S2) {#s2}

Proves the *architecture* (running start + structural handoff), not sub-meter
precision.

## 41-flight forensics (why fast crossers miss ~1.4 m) {#zem}

Miss tracks zero-effort-miss at handoff with r² = 0.96 — *variance explained*,
never "96% of any one miss" (the runbook's DEEP-H5 rule). The forensics set is
the 6 m/s cue-era campaign (n=41, ADR-0023); the r² sharpens toward 0.99 at
higher speeds (ADR-0069), where correction capacity shrinks against delivered
ZEM.
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

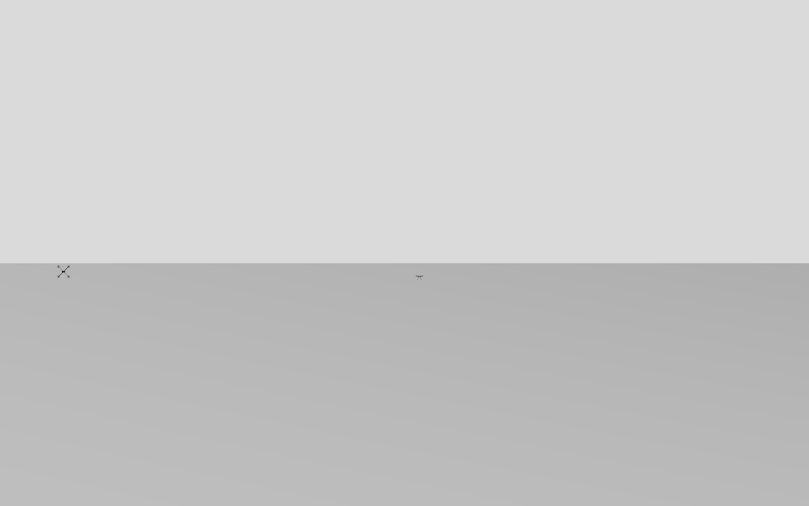
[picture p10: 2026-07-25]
tests/fixtures/field_selftest_frame.png

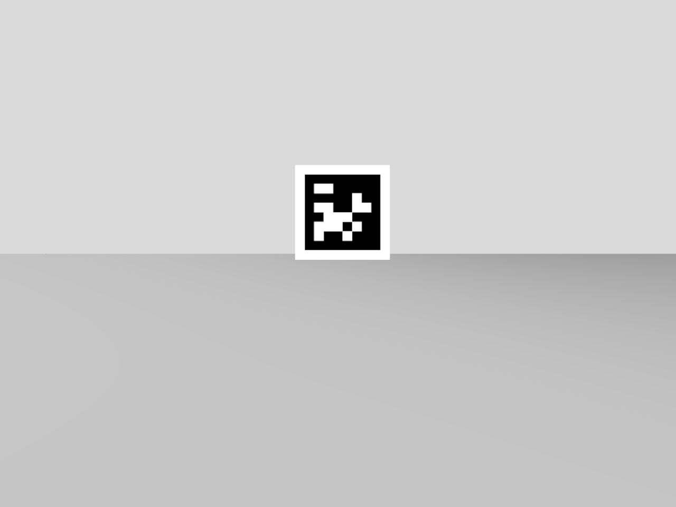
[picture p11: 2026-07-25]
tests/fixtures/apriltag_sim_frames/fwd002.0_y+0.0_0000_r001.9.png

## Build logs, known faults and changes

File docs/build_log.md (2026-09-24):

# Project Log

A running log of how this project has actually gone, the process more than the results.

*Note for an AI organizing this log: the written contents should not be changed except for spelling errors and light formatting/structure cleanup (which I've sanctioned). The formatting of each entry may be adjusted, just not the core contents.*

## Pre-part work

With extensive planning and Claude Code usage, most software has been set up ready to install for the first of the test campaign. I started with identifying goals for the project, methodology for testing the goals, and the best way to go about AI usage in making a project with far too much software for myself alone manageable and realistic.

Extensive time was spent with project management, as project files quickly ballooned well above frontier context limits. Workflows, an extremely detailed project CLAUDE.md, and use of a Fable head were crucial for useful AI work. Furthermore, ensuring code would actually work was done via the use of a drone simulator, running as much of the code as possible to catch errors and logical faults I missed.

The biggest hurdle to overcome was the standard limitations of LLMs today, listed below with a significant example of each.

- **Overly agreeable sentiment** that would have a difficult time saying no to a certain methodology or project aspiration: The initial aspirations for building a visual Neural Network ready to use on the flight hardware I could afford, entirely with the simulator. Claude seemed to think it possible, but after extensive testing with the sim-built neural network I came to the conclusion we could not get around onboard compute constraints or sample size constraints (at least using simulator only and public datasets). Another good example of this was seeing intercept distance numbers that looked excellent, only to realize the sim didn't simulate vertical separation or vertical homing at all! Other sim measuring issues worked against me the other way, measuring intercept distance at the wrong time and frustrating me as to why numbers suddenly got so bad. Monitoring at least one run per sim batch on the GUI became important. Issues like these also quickly went away as Opus 4.8 left.
- **Context holes** overlooking important challenges: Definitely part of the learning curve orchestrating a project with so many moving parts. Something so simple as how I would mount the AprilTag that the seeker would track to the target drone, that I didn't consider until right as I was ordering parts. I quickly learned I was not nearly thorough enough in building diagrams and techniques to catch constraints in both hardware and software, and had to adapt quickly.
- **Context management:** Despite hundreds of prior hours spent at the head of agents, far less capable than Fable at context management, I still hit my limits with keeping important project details cached for models to consider. Striking a good balance of model guidelines while not overloading CLAUDE.md and other project management docs was a difficult time, and led me to regret not using Obsidian. I overcame this (and aforementioned constraint identification and resolve) primarily with a Claude-created interactive artifact that I could access from any device and track the status of each moving part of the project ([link to the artifact](https://claude.ai/code/artifact/eb5e40d1-c12a-4b87-bca0-589ad5af96fc)). Claude and myself would reference and update that before anything else when working a respective issue to ensure important holes wouldn't go uncaught. Keeping up with the latest ways to handle Opus and Fable in these regards were important as well as they shifted in context strategy considerably.
- **Actually using Fable:** My project is Fable safeguards' worst nightmare in nearly all regards, but also relied on its abilities heavily. The head agent, particularly for the first 2/3 of the software-only phase, would get knocked to the then-available Opus 4.8 within minutes of days-long work sessions. I initially worked around it with Fable subagents to review the work and attempt project housekeeping outside the scope of the actual intercept code development, which was a large inconvenience. Opus 5 was a significant upgrade in this regard as it gained many of the Fable abilities I relied on heavily. Once I worked through the majority of the interceptor code and shored up the project files, I got the head pretty good at using subagents for all potentially flagged work, meaning at worst Opus 5 would handle a small part of the development while retaining Fable's superior management. (This was token expensive, but worth it as I heavily reduced needing to redo elements.)

Solving or reducing each of these issues naturally helped the others as well, which made project work get far more efficient and usable rapidly and exponentially, something I valued hugely and allowed me to retain motivation despite the setbacks. Ordering parts was relatively straightforward: I organized what I expected to have to buy, turned Claude loose on a build order and cowork session to load carts, and carefully scrutinized the selections against my own with the help of another detached Claude session evaluating constraints I had found against selections. This session was also the most important for handling the cost constraint against real hardware I needed. The careful picking allowed me to get a final parts list superior to both my own and Claude's, although it was reassuring to know either would have probably worked great. The biggest assets I came into the project with were core understandings of how LLMs work, and knowing exactly which questions to ask as work went on to identify gaps, programs I should be using, tools, and being determined to understand the workings of each subsystem within the project.

## Hardware-arrived work

Getting hardware made me feel like a kid on Christmas, finally getting to put what I had been working on into actual things and getting to spend time doing the satisfying work of seeing my choices actually work and come together. Claude was a lovely work assistant when I was unsure of how exactly parts would go together. Most of the initial build phase went smooth; however, I ran into troubles with some connectors on the Pixhawk 6C selected not working with the DuPont cables I needed for the Raspberry Pi interface (this is on the interceptor side of the hardware). Some splicing, heat shrink, and wiring diagrams Claude found made this a 5-minute fix that worked like a charm. I learned about safe handling of the lithium polymer batteries used as well. Raspberry Pi software loading was a breeze; once I got it on my local network I used SSH and my Claude CLI connected and handled it all beautifully (with a brief final code review). Pixhawk flight software was also straightforward.

## New entries (append below)

## Bench integration and the chase pivot

All GPS units sorted; soldering to the H7 was a bit tricky. Flight software interfacing to Claude was a piece of cake, and made getting flight code on device no problem.

After a week of excellent progress getting intercept distances down, I made the switch to a dash-then-chase intercept. It extends the distance and time to intercept, but allows for hugely faster moving targets, much higher rates of intercept, and should give me the ability to code in a last-second abort so I can do numerous runs, without destroying hardware, while being pretty sure of a collision. Additionally, it will give an NN more time to identify and track a drone with confidence and free up compute.

I ran into a major safeguard issue out of nowhere. Fable had been handling more and more work I needed, having an excellent setup for scope and task delegation to subagents. Suddenly, any prompt instantly triggered safeguards on Fable or Opus. After 4 very frustrating days, I realized an update to the CLI had switched the default model to Fable 5.1. While I use that model for other projects and love it, its safeguards were responsible, and deliberately using Fable 5 solved my issue entirely.

Using a new sim, isim. Less powerful in general, but I can do thousands of runs in a second instead of the painfully slow Gazebo. I've been using isim now with Gazebo verification once I like an upgrade. I wish I had discovered this sooner, and would do more research on sims if I were to undertake another project like this before going so aggressive on the software. I am happy with intercept rates and I think I am ready for the Tier 2 build, and I will start verifying the list and ordering parts soon.

## Target bench: wiring battles, motor mapping, and the biggest setback yet

I made a lot of progress the past few days on bench. I connected the antenna, got motors wired into the ESC, and the ESC mounted to the board. Tackling the battery and power wiring was more complex than I expected. I had trouble soldering the leads directly into the connector it came with, and decided the best bet was cutting it off and instead connecting wire to wire for the PM02 power module. It went great, until I realized I had chopped off the wrong damn connector while getting ready to plug in the battery outside. Definitely demotivating. While I initially was ready to order a new PM02 (despite mostly China stock), I managed to solder on the connector with a lot of patience and heat shrink. I finished up the new connections, had to replace a different connector that was gunked up with solder and wouldn't go into the smoke stopper, and finally got to plug the battery in.

The initial setup went good, with Claude testing functions through the FC with a USB connection, and mapping motors and directions based off me telling it what happens with what inputs, and finally I fully went to connect the FC to the frame, thoughtfully place GPS and antenna, do cable management, and was seeing the end of the road for the target drone. This is where I hit the biggest setback of the project yet. In the tightly packed zip-tied setup, two wires (I still don't know exactly which two) for the GPS module or antenna crossed due to poor soldering and exposed lead where I had stripped too much wire. Potentially it was the carbon fiber frame joining the wires as well (now I know carbon fiber is pretty conductive). Claude picked up a fault in the baro. What I thought would be a quick fix took an entire night of troubleshooting, eventually leading me to getting voltages with a multimeter suspecting a dead bus. I tried isolating the FC from the GPS unit, multiple restarts, different boot methods, careful inspection of solder connections, isopropyl and a toothbrush for flux, and eventually got voltage readings of 1.4 instead of 3.3 on SCL and SDA to ground. My physics 2 knowledge led myself and Claude to suspect an unpowered board would have a resistance of 1–2 kΩ if my theory was correct about the dead bus. It did, and that ended the night with a new FC on the way — and while I am frustrated, I definitely learned a lot through the process.

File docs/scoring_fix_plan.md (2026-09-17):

# Scoring-integrity fix plan — issues #8, #9, #3 (planned 2026-08-10)

> ## ⚠️ §2's #8 SECTION IS CORRECTED — read this first (2026-08-10, after the offline re-score)
>
> This plan was written against issue #8's premise that the scorer sits **+0.208 m above** the
> airframe datum. **That is wrong.** The figure is `median(gt_cam_z − alt_m)`, and `alt_m` is
> MAVSDK `relative_altitude_m` — height above the takeoff point, not world z — so it measures the
> **landing gear**. The camera is **~2 mm** above the datum and **0.120 m forward**. The
> correction is horizontal, not vertical.
>
> **Three things in this plan are therefore wrong, and one of them is dangerous:**
>
> 1. **§2's proposed m4 change would make the scorer WORSE.** It says return `p_model`
>    (`tracker.latest[DRONE_MODEL]`) "as base_link". `p_model` is the model origin, **0.240 m
>    BELOW** `base_link` — essentially the gear datum. Scored that way the adopted config reads
>    13/16, a *larger* error than the camera reference it replaces, in the **flattering**
>    direction. The correct additive column is `p_model + 0.240·(body up)`, or log the attitude
>    quaternion and compose downstream.
> 2. **The expected result is 3/16 → 5/16, not 3/16 → 12/16 → 16/16.** §4's surface-sweep list is
>    still right about *where* to sweep; the numbers to write there are different, and they do not
>    flip the headline.
> 3. **§6 risk 6b is void.** The wind/error-correction workflow's vertical sizing was NOT built on
>    a measurement artefact — the −0.37 m vertical bias is real (re-measured: median −0.374 m at
>    the corrected c2c CPA vs −0.375 m at the camera).
>
> **§1 (the ORDER), §3 (the re-fly budget) and §5 (#3's pre-registration) are unaffected** — they
> turn on which arms are contaminated by which defect, which does not depend on the lever arm.
> Evidence: `docs/rescore_2026-08-10.md`; tool: `scripts/rescore_cpa.py`.

**Scope:** the three open measurement-layer defects — the wrong-reference scorer (#8), the
coded-dash zero-command bug (#9), and the informationless past-CPA breakoff (#3). All three
either contaminate camera-arm results or misgrade every result; two of them are arm-asymmetric
in the direction that penalises the camera. This plan exists to fix them **in an order that
flies the sim exactly once**, and to sweep every published number the fixes flip.

**Sources:** GitHub issues #8/#9/#3 · `docs/flight_plan_candidates.md` §"THE RULER WAS WRONG"
(lines ~1263–1312) and §"TWO HEAD ERRORS CORRECTED" (ERROR 3, lines ~1113–1123) ·
`scripts/m4_intercept.py` · `scripts/m3_static_intercept.py:311` · ADR-0062, ADR-0084,
commits `0c80454`, `1b51fb4`.

**Hard constraints honoured throughout:** the ram radius stays **0.35 m** (ADR-0084 — no
compensating inflation); dead-band re-tries are graveyarded (measured-out, do not revisit);
every re-stated number keeps the **best-case-upper-bound framing** (perfect launch cue —
ledger `launch-aim-derived-from-ground-truth` — co-altitude by construction, no wind).

---

## 1. THE ORDER

**#8 → #9 → #3 (all three landed and tested), THEN one combined camera-arm re-fly. Zero
flights before that point.**

1. **#8 first — fix the ruler before anything flies.** It is the only fix that changes the
   *meaning* of every flight, and it needs **zero sim time**: every historical arm re-scores
   offline from the per-tick `gt_*` columns already in `logs/`. If anything flew before #8
   landed, its verdict would be computed against the lens-referenced, logged-tick ruler and
   would need re-adjudication afterwards. Fixing the ruler first means no flight in this
   project is ever scored twice.
2. **#9 second — a one-line control-flow fix plus tests, still zero flights.** The fix is
   verifiable by unit test + auditor upgrade + a single canonical-geometry demonstration
   flight; the *fleet-level* verification rides the combined re-fly.
3. **#3 third — validated offline before it flies.** The first-candidate discriminator
   (`--breakoff-max-range-m`, see §5) is already in the codebase and its separation power is
   already measured on existing logs (27 breakoff events, five arms). Adoption is decided by
   the same combined re-fly.
4. **One combined camera-arm fleet, on a frozen HEAD containing all three fixes**, at idle
   load, serial, no workflows running. This single fleet triple-serves as: the #9
   fleet-verification (auditor count = 0), the #3 adopt/reject measurement (premature-breakoff
   rate against ground truth), and the refreshed camera-vs-dash verdicts on the correct ruler.

**Why this order minimises re-flying:** #9 and #3 both live in the ENGAGE terminal, so both
contaminate *only camera arms* — the same ~40 flights. Fix them serially with a fleet between
each and you fly those 40 flights two or three times (the project already flew this exact
fleet once, `1b51fb4`, and #9/#3 were both live during it). Fix everything first and the
fleet flies once. #8 forces no flights at all, ever — it must simply land before the fleet so
the fleet's pre-registered criteria are stated against the correct ruler on day one.

**Why no fix lands on a contaminated baseline:** the fleet's dash-only comparison twins are
**re-scored, never re-flown** (they never ENGAGE — structurally immune to #9 and #3; #8 is
scoring-only). Pairing survives because the twins are reused with the same master seeds
(the review-2 rule). The camera arms' *new* numbers are compared against the *re-scored*
twins, so both sides of every A/B sit on the fixed ruler.

**Sequencing around the live wind/error-correction Workflow** (its wiring agent is editing
`scripts/m4_intercept.py` now): see §6, risks 5–6. Short version: land #9 and #8's small m4
touches as isolated, coordinated commits (most of #8 lives in a new module + standalone
re-scorer precisely to shrink the merge surface); the fleet flies only **after** the workflow
lands, with wind proven default-off/byte-identical — and never while its agents are running
(the 2026-07-26 load-confound VOID).

---

## 2. THE FIXES

### #8 — score centre-to-centre, at the true closest approach

**Concrete change**
- `scripts/m3_static_intercept.py:311` `ground_truth_world_points()` already holds the
  interceptor **model origin** (`tracker.latest[DRONE_MODEL]` → `p_model`) before composing
  the camera. Return it too. Target end unchanged: `fpv_quad_enemy`'s origin IS its airframe
  centre (verified, frame visual offset 0.025 m).
- **Additive CSV columns**, not a semantic change: `gt_intc_x/y/z` (base_link world) and
  `gt_range_c2c`. `gt_cam_*`/`gt_range` keep their current meaning — 16 downstream files read
  them (`render_hud.py`, `eval_seeker_v3.py`, `ekf_ab_analyze.py`, `audit_per_tick.py`, …);
  silently changing their semantics is exactly the schema-break class that bit this project
  twice. Also add the attitude columns (quaternion or roll/pitch) ADR-0062 deferred — they
  close the historical-reconstruction problem permanently (risk 4).
- **Scoring switches to c2c + interpolated CPA** at all three scoring sites:
  `min_gt_range_running` (`m4_intercept.py:4051–4053`), `recompute_min_gt_range_from_csv`
  (`:1691`), and the RESULT cross-check (~`:4859`). Interpolation: linearly interpolate BOTH
  world positions across each tick pair; |Δp(t)|² is quadratic per segment with a closed-form
  minimum. Report three numbers per flight: **c2c interpolated (primary)**, c2c logged-tick
  (conservative check), lens logged-tick (legacy continuity, labelled as such).
- **Standalone re-scorer** `scripts/rescore_cpa.py` (new module — keeps the m4 diff small):
  new-format logs use the exact `gt_intc_*` columns; historical logs reconstruct base_link
  from `gt_cam_*` minus the mount lever arm (vertical 0.208 m — measured, median over 1,748
  ticks; forward 0.12 m rotated by logged `psi_deg`; pitch/roll approximated — see risk 4 for
  the calibration bound). AprilTag/billboard-era logs get the lens correction only, with the
  target-reference caveat stated (centre==origin verified only for `fpv_quad_enemy`).
- **The radius does not move.** 0.35 m, ADR-0084, restated here so nobody "balances" the
  ruler fix by inflating the criterion.

**Proof it is not inert**
- **Producer→consumer contract test**: the fixture CSV is generated by `m4_intercept.py`'s
  OWN `write_row`/`CSV_HEADER` on synthetic ticks — never hand-typed (hand-typed fixtures are
  what hid both prior schema breaks).
- **Mutant test (required by the issue)**: on a fixture with a non-zero lever arm and a
  between-ticks crossing, assert scorer output equals the centre-based interpolated value AND
  differs from both the lens-based and the logged-tick values. Re-pointing the scorer at
  `gt_cam_*` (the restored defect) makes this test FAIL.
- **No-vacuous-verdict**: empty/NaN gt columns → exit ≠ 0, never a number.
- **End-to-end demonstration**: `rescore_cpa.py` over `logs/mc_fp_armAE5dash_line9_s{123,777}.csv`
  must reproduce the head's ad-hoc table — 0.445 m / 3/16 → 0.293 m / 12/16 → ~0.237 m /
  16/16 — from the shipped tool. If the shipped tool does not move those numbers, the fix
  did not ship.

**Evidence to regenerate:** a full old-vs-new re-score table for every arm in `logs/`
(`mc_fp_arm*`, `mc_speed10_*`, loft-dive A/B/Adash/Bdash, and the M5-era batches with the
era caveat), committed as a doc + ADR — old numbers reported alongside, never silently
relabelled. Then the §4 surface sweep, same turn.

### #9 — the coded-dash `last_cmd` hole

**Concrete change**
- `scripts/m4_intercept.py:3370–3371`: the `--coded-dash` branch builds `cmd` and never
  writes `last_cmd`; add `last_cmd = cmd`, mirroring the S2 dash branch at `:3577` (which
  already does it). Consequence to state in the commit: a terminal dropout in the first
  ENGAGE ticks now **holds the dash command** (keeps closing) instead of re-issuing the
  `(0,0,0,0)` initialiser from `:2730` — i.e., the dropout handler at `:4009–4012` finally
  does what its comment says.
- Check the other `last_cmd` readers see sane values on this path: `:3539`, `:3897`,
  `:4039` (`hold_yaw`).
- **Hardware parity, same turn** (the frozen_vworld lesson — one code path): verify
  `flight/deploy/seeker_loop.py` and `flight/deploy/real_flight.py` do not carry the twin
  defect in their dropout/hold paths; if they do, fix there too before any bench work
  inherits it.

**Proof it is not inert**
- Unit test driving the tick logic dash → ENGAGE → dropout-on-first-tick, asserting the held
  command equals the dash velocity and is not the zero initialiser.
- **Auditor upgrade — the existing instrument provably missed this**: `audit_per_tick.py`
  check (e) fails only at >50% zero-command ticks; this bug produced 24 ticks across 5/16
  flights and sailed under it. Add check (f): ANY pre-CPA ENGAGE dropout tick whose command
  is exactly the `(0,0,0,0)` initialiser → FAIL. Run (f) over the OLD logs and show it
  fires (the instrument can see the defect); run it over a post-fix flight and show 0.
- Mutant: revert the line; the unit test and check (f) must both fail.
- **One canonical demonstration flight** (not a fleet): reproduce the worst measured case —
  the flight that held 5 consecutive zero ticks while closing 7.3 → 4.6 m at 13 m/s — using
  the canonical master-seed geometry extracted from the baseline log (the
  reproduce-canonical-gate-geometry rule; arm definitions at
  `scripts/experiments/flight_plans/run_arm.sh:88–104`). Show the dropout now holds the dash
  vector.

**Evidence to regenerate:** audit (f) = 0 across the combined fleet (§3); the camera-arm
verdict refresh itself rides that fleet.

### #3 — the past-CPA breakoff discriminator

**Concrete change** (per the §5 pre-registration, which is written before any flying)
- **First candidate is NOT a new estimator** — see §6 risk 1. Turn on
  `--breakoff-max-range-m 5.0` (flag exists at `m4_intercept.py:2169`, wired at
  `:3989–3992`, shipped inert by ADR-0062 FIX-B): gate breakoff on the ABSOLUTE measured
  range at fire time — a different signal from the measured-out per-step rise magnitude.
  Adopt it into the canonical camera-arm config (`run_arm.sh`) and the `--fpv` defaults.
- Offline validator script that replays historical per-tick logs and counts
  premature-vs-legitimate breakoffs under the gate — it must reproduce the already-measured
  separation (blocks 6/7 premature including every catastrophic r2l flight; suppresses 2/24
  legitimate, both at `closed_after = 0.00` where CPA was already recorded).
- Port the decision to `flight/deploy/real_flight.py` (its breakoff arms at 4.0 m —
  harmonise the constants deliberately, don't let sim and hardware drift).
- The dead-band/min-rise family stays graveyarded. Nothing here re-tries it.

**Proof it is not inert**
- Unit test of the `range_ok` clause (fires blocked above threshold, unaffected below).
- The offline validator reproducing 6/7 vs 2/24 on the historical logs — the instrument
  agrees with the hand measurement before anything flies.
- The combined fleet (§3) measured against ground truth: premature-breakoff rate collapses
  from ~29% (10 mph) / 10–16 mentions per 8-flight arm (9 m/s) to the §5 criterion.

**Evidence to regenerate:** the fleet's premature/legitimate breakoff counts per arm; the
speed-ladder UNBLOCK note (the ladder stays blocked until §5's criterion passes); an ADR
recording adoption or the NULL.

---

## 3. THE RE-FLY BUDGET

**Total: 40 flights (48 with the optional arm), flown once, in one idle session, after all
three fixes land on a frozen HEAD.** ~70–90 s/flight plus boots ≈ 1.5–2 h serial.

| arm | flights | action | why |
|---|---|---|---|
| AE5dash s123+s777 (adopted config), AAL, G20dash, AE15dash, AE2dash, AE7dash, EAL, speed10-dash | 0 | **re-score offline only — never re-flown** | dash-only arms never ENGAGE: structurally immune to #9 and #3; #8 is scoring-only |
| G20 s123, G20 s777 | 16 | **re-fly** (fleet) | the "camera ≈ parity at correct aim" claim — the most load-bearing camera verdict |
| AE5 s123 | 8 | **re-fly** (fleet) | aim-error null adjacent to the adopted config |
| AE15 s123 | 8 | **re-fly** (fleet) | the wider-aim-error null; feeds the cue-error sweep next |
| speed10 camera s123 | 8 | **re-fly** (fleet) | 29% premature-breakoff rate — the #3 validation rung, and the ladder's gate |
| GL s777 (190 ms LOS-lag comp) | (8) | **recommend DROP** | the lever is already closed-negative and both GL and G20 are camera arms (defect hits both sides); direction robust. Re-fly only if the builder wants "closed" re-earned. Saves 8 flights. |

**Sharing — the point of the whole plan:** this ONE fleet is simultaneously (a) #9's
fleet-verification (audit (f) = 0 across all arms), (b) #3's adopt/reject measurement
(§5 criteria, scored against per-tick ground truth), and (c) the refreshed camera-vs-dash
verdicts on the correct ruler, paired per `run_idx` against the **re-scored** dash twins.
No fix gets its own fleet.

**What mis-ordering would cost, concretely:** fleet after #9 but before #3 → breakoff
contamination persists (it fires on ~every camera flight) → a second 40-flight fleet. Fleet
before #8 → pre-registered pass bars adjudicated against the lens ruler → re-adjudication
and, if any verdict is marginal, a credibility re-fly. The project has already paid for one
full fleet (`1b51fb4`) that #9/#3 were live under; this plan makes the next one the last.

**Opportunistic, not required:** the VOID'd 10 mph **aim-trim sweep** (dash-only, 4 arms × 8
= 32 flights, pre-registered in `flight_plan_candidates.md`) depends only on #8 (its decisive
criterion is Pk@0.35). It may fly in any idle window once #8 lands — before #9/#3 if
convenient — because dash-only arms cannot express either bug. Keep it a separate session
from the fleet; never overlap batches.

---

## 4. WHAT MUST BE RE-STATED PUBLICLY (same turn the re-score lands)

Numbers that flip when #8 lands, and every surface that carries them:

| currently published | becomes | where it appears |
|---|---|---|
| "Nothing yet lands inside the 0.35 m ram radius (0/16)" | AE5dash: **12/16** inside 0.35 m at logged ticks, **16/16** interpolated, median 0.293/0.237 m — as a perfect-cue UPPER BOUND | `docs/next.md` §"Where the project is" (also stale vs ERROR 1's 3/16 **today**) |
| kill-stage caption "So far 0 of 16 sim flights get that close" | same correction | `docs/project_state.json` stage `kill` caption + note |
| AE5dash "median 0.445 m, 3/16" | 0.293 / 12/16 (logged), 0.237 / 16/16 (interp) | `docs/flight_plan_candidates.md` (correction already drafted there — mark SHIPPED), ADR-0083 quotes |
| dash floors "0.71 m / 0.43 m" (ADR-0080/0083) | re-scored values from `rescore_cpa.py` | `project_state.json` stage `coded_dash` note, `docs/real_build_coded_dash.md` |
| "the terminal must earn ~1 m" | re-derived gap at the centre datum (near zero for the adopted config **under a perfect cue**) — this changes the airframe-size discussion the kill note already flags | `docs/hardware_order_list.md` §0b/§0c, stage `kill` note |
| "the miss is vertical, −0.37 m" | ~−0.16 m real vertical after removing the 0.208 m lens lever (direction stands, magnitude halves) | anywhere the vertical-offset finding propagated (check the wind/error-correction workflow — §6 risk 6) |
| camera-vs-dash margins & "camera makes it worse" attributions | re-stated from the fleet; until then, margins remain "not quantitative" (already softened) | `project_state.json` stage `terminal`, `README.md` results rows, `docs/next.md` |
| M5-era "median 0.93 m, n=96" | keep, footnoted "lens-referenced, logged-tick, billboard era" (or re-scored with era caveat) | `project_state.json` `key_numbers` |

Mechanics per the CLAUDE.md ritual: edit `project_state.json` → `render_dashboard.py` →
**republish the Artifact to the same URL** → commit; sweep `docs/next.md`, `README.md`, dashboard
§0 headline/hero the SAME turn. Ledger: add-and-resolve `scorer-measured-camera-lens`.
Assumptions register: scoring reference moves to `measured`. Graveyard: dead-band entry
stays. New ADRs: one for #8+#9 (instrument fix + re-score), one for #3 (adoption or NULL).

**Framing rule for every re-stated number:** perfect launch cue, co-altitude by
construction, no wind, sim optics — so "the adopted config meets the contact criterion in
sim **under a zero-error cue**" is the maximal honest claim. Not "we reach contact in the
field." The 16/16 must never argue for skipping the cue-error sweep — that constraint is
exactly what the sweep exists to remove.

---

## 5. PRE-REGISTRATION — #3's replacement discriminator (written before any flying)

**Candidate signal:** the ABSOLUTE measured range at which the breakoff fires
(`--breakoff-max-range-m 5.0` — in-code, documented deployment value under `--fpv`). This is
a different signal from the measured-out per-step rise magnitude: legitimate breakoffs fire
at measured 1.60–2.40 m (20/22), premature ones above 3.1 m (6/7), across 27 recorded events
on five arms. Registered fallback if it nulls: an own-state kinematic passage test (own-EKF
displacement since ENGAGE ≥ initial `r_hat` minus margin — you cannot have passed a target
you have not yet flown far enough to reach), as its own design change with its own pre-reg.

**Config:** canonical camera arms (`run_arm.sh`), gate ON at 5.0 m, everything else frozen at
the post-#8/#9 HEAD. Decided on the §3 fleet — no dedicated arms.

**Predictions:**
1. Premature breakoffs (defined against ground truth: breakoff fires, then true range closes
   > 0.5 m further) collapse from 2/7 (10 mph) and 10–16 mentions/arm (9 m/s) to ≤ 1 across
   the 16 flights of the 10 mph + AE15 rungs, and ≤ 1/40 fleet-wide.
2. Legitimate past-CPA breakoffs still terminate at least as many flights as pre-fix, within
   1.5 s of true CPA; at most one flight converts to an ENGAGE-timeout abort instead.
3. No phantom-chase regression: flights that would previously have broken off early do not
   keep steering > 2 s past true CPA (the honest caveat from ERROR 3 — suppressing an early
   breakoff does not automatically help; this measures it). ≤ 1/40.

**Adopt iff all three hold.**

**What a NULL means (stated now):** if premature breakoffs persist ≥ 2 among the 16
slow/wide-error flights with the gate ON, then the *threshold family* is exhausted — both the
per-step rise AND the absolute range have been measured and failed — and the discriminator
must move to the own-state kinematic fallback as a design change. The speed ladder **stays
blocked**. The cue-error sweep may proceed only with the breakoff disabled and
`ENGAGE_TIMEOUT_S` as the sole backstop, disclosed as a sim-only concession — or it waits. A
null here does NOT license revisiting dead-bands, and it does not impugn the #8/#9 results
(they are independent of which discriminator fires).

**Threshold-portability rule (binding):** 5.0 m is validated only in the 4.5–10 m/s regimes
these logs cover. Every new speed rung re-earns the threshold OFFLINE from that rung's first
camera logs (fire-range distributions, legit vs premature) before that rung's verdict counts
— per the "a threshold validated at one operating point is not validated at another" rule.

### 5b. The first candidate FAILED its offline check; the registered fallback is promoted (2026-09-17, written before any flying)

**The 5.0 m absolute-range gate does not reproduce.** §5 rests on "blocks 6/7 premature, suppresses
2/24 legitimate, across 27 events". An independent replay written tonight
(`scripts/forensics/breakoff_gate_replay.py`, 5 self-tests, every arm row bucketed: 56 rows →
47 judged, 7 never broke off, 2 broke off for another reason, 0 dropped) over seven camera arms
finds **47** range-increase breakoffs, **9 premature**, and the 5.0 m gate blocks only **5/9** of
them while suppressing 4/38 legitimate. The four it misses fired at a *measured* range of 1.76,
1.89, 3.13 and 4.92 m while the target was truly 4–9 m away — the monocular range under-reads
badly far out (`range_channel_horizon.py`, 2026-09-11), so **any gate built on the measured range
inherits the fault it is trying to catch.** §3 of this plan required the offline separation to be
reproduced before the gate flies; it was not, so the gate does **not** fly. Both threshold
families (per-step rise, absolute range) are now measured out.

**Promoted: the own-state passage test** — *you cannot have passed a target you have not yet flown
far enough to reach.* `--breakoff-min-flown-frac F`: the range-increase breakoff may fire only
once the vehicle's own displacement since the dash began (own EKF position) is ≥ F × the
pre-flight lead solve's own intercept distance. Built tonight, default OFF, truth-tabled,
fail-closed on a missing input, wiring pinned by test. Honesty: own-state plus a pre-flight
constant that comes from the same launch cue already declared given (`launch-cue-error-free`);
nothing about the target is read in flight. Offline on the same 47 events it blocks **9/9
premature** at F = 0.7, 0.8 and 0.9 alike (largest premature fraction 0.70; smallest clearly
legitimate 0.80+), and **3/38 legitimate**, all three with closest approach already recorded.
F = **0.8**, mid-gap. The offline replay uses true position as a stand-in for the EKF's.

**Fleet (seed 123 — the canonical geometry the events came from; HEAD carries issue #9's fix):**
`AE15N`/`AE15P` (9 m/s, 15° aim error) and `S10N`/`S10P` (10 mph rung). N = gate off, P = gate on
at 0.8, so #9's effect is not credited to the gate. n = 8 each, sequential, idle load.

**Predictions (same three as §5, restated for this gate; premature = fires, then true range closes
> 0.5 m more):** (1) premature breakoffs across the 16 P-flights ≤ 1, against ≥ 2 across the 16
N-flights; (2) no P-flight that the gate holds keeps steering > 2 s past true closest approach;
(3) at most one P-flight ends by ENGAGE timeout that its N-twin ended by breakoff.
**Adopt iff all three hold.** Auditor check (f) must read 0 offending ticks on all 32 flights
(issue #9 observed fixed end-to-end).

**What a NULL means:** if ≥ 2 premature breakoffs survive with the gate ON, the own position or
the plan distance is not what the offline replay assumed (EKF position vs truth, or the dash
start latch) — debug that before touching the threshold. If the N-arms show < 2 premature, the
fleet is underpowered to show anything and says so. The speed ladder stays blocked either way
until this adopts.

**Portability (binding):** F = 0.8 is earned at 4.5–9 m/s crossing targets with a solved heading.
An explicit `--dash-heading-deg` has no plan distance, and the gate then fails closed by design.

### 5c. RESULT of the §5b fleet, seed 123 (2026-09-17) — the gate works; the criterion as I wrote it is NOT met; the camera is no better for it

32 flights, HEAD `226eb1a`. Auditor check (f): **0 offending ticks on 32/32 flights** — issue #9 is
observed fixed end-to-end.

| | gate OFF (`AE15N`+`S10N`) | gate ON (`AE15P`+`S10P`) |
|---|---|---|
| premature breakoffs (fires, then true range closes > 0.5 m) | **5/16** (closing 1.5–2.8 m more) | **1/16** |
| flights ended by ENGAGE timeout | 0 | 0 |
| 10 mph rung, median miss | 0.84 m | 1.00 m |

- **Prediction 1 HOLDS** (≤ 1 with the gate, ≥ 2 without). The one survivor (`AE15P` #1) sat at an
  offline flown/planned fraction of 0.76 — inside the 0.8 gate on true position, yet the in-flight
  gate let it through. The vehicle's own position estimate and the truth differ by a few tenths of
  a metre at 16 m/s; the gate has no margin for events that close to the line. Named in §5b's null
  clause; not a threshold to retune on one event.
- **Prediction 3 HOLDS** (no breakoff converted into a timeout).
- **Prediction 2 FAILS as I wrote it.** §5b says *no* gate-held flight may keep steering > 2 s past
  true closest approach; `S10P` #5 was held and steered on for 2.54 s. §5's original wording
  tolerated ≤ 1/40 and would have passed; I wrote the stricter word and am held to it.
  **NOT ADOPTED on this fleet.** Context, not excuse: steering 2–3.7 s past closest approach
  happens on 6/8 `S10P` flights and on 2 of the 4 `S10N` flights that reached closest approach at
  all, including flights the gate never touched — the breakoff fires LATE as well as early. That is
  its own defect (irrelevant to the miss number, relevant to a real vehicle flying on past its
  target) and is logged as such.

**The result that matters more than the gate.** Taking the early quits away did not help the camera:
pair by pair on the 10 mph rung the four flights that used to quit early went 1.70→0.83,
0.89→1.72, 0.84→1.09, 1.45→1.22 m, and the arm median went 0.84→1.00 m against the dash-only
twin's 0.73 m. The plan warned of exactly this ("suppressing an early breakoff does not
automatically help"). The premature breakoff was the one defect only the camera arm could suffer,
and it was the standing reason the camera-vs-dash margins could not be quoted. With it 80%
removed, the camera still does not beat a well-aimed sprint at 10 mph. **The null is no longer
confounded by this defect** — n = 8, one seed, so it is a direction, not a margin.

**Replication, registered now, before it flies:** the same four arms on seed **777**, judged on
§5's ORIGINAL wording (premature ≤ 1/16 with the gate; phantom-chase attributable to the gate
≤ 1/16, where "attributable" = a gate-HELD flight steering > 2 s past closest approach whose
gate-off twin did not; timeouts ≤ 1). Adopt iff seed 777 meets all three AND seed 123's clause-2
miss stays the only one across the 32 gate-ON flights. Anything else: not adopted, and the speed
ladder runs with the breakoff disabled and the timeout as backstop, disclosed as a sim concession.

**LOAD CONTAMINATION, MY ERROR (2026-09-17 ~07:33–07:38Z).** While the seed-777 replication was
flying I ran pytest and then the full `scripts/run_tests.sh` on the same machine; 1-minute load
reached 7.1 against the ≤ 1.5 the batches are gated on. That overlapped the end of `AE15N` and the
start of `AE15P`. The idle-load rule exists because load changes the sim's real-time factor and
the detector's cadence (ADR-0015 2nd addendum). **Both seed-777 `AE15` arms are DISCARDED unread and
re-flown after the fleet ends**; `S10N`/`S10P` flew with nothing else running. Process fix for the
rest of the session: no test suite and no bulk log analysis while a batch is in the air.

### 5d. REPLICATION, seed 777 (clean re-fly) — the gate does its job perfectly and is STILL not adopted; the window version is registered

| | gate OFF | gate ON |
|---|---|---|
| premature breakoffs, seed 123 | 5/16 | 1/16 |
| premature breakoffs, seed 777 | 6/16 | **0/16** |
| breakoff → timeout conversions | — | 0 and 0 |
| gate-HELD flights steering > 2 s past closest approach when their twin did not | — | 1 (seed 123), **2 (seed 777; one for 7.0 s)** |
| median miss, 10 mph rung (123 / 777) | 0.84 / 0.88 m | 1.00 / 0.79 m |
| median miss, 15° aim-error rung (777) | 1.47 m | 1.42 m |

Clauses 1 and 3 hold on both seeds (premature breakoffs **11/32 → 1/32**). Clause 2 — registered
as ≤ 1/16 attributable phantom-chases — reads **2/16** on seed 777. **NOT ADOPTED, as registered.**
No threshold is being moved.

What the failure is telling us: the range-increase rule was doing two jobs badly. It quit EARLY
(the gate fixes that) and it is also the only thing that ends the terminal AFTER the pass — and
it is just as unreliable there. Hold it back and some flights simply keep steering at whatever
the camera reports (mostly the ~1.5 m own-airframe phantom) for seconds. The same own-motion
idea closes the other side: **across all 64 camera flights tonight, true closest approach always
came by 1.05× the planned intercept distance** (p10 0.80, median 0.92, max 1.05 — including the
15° aim-error arms). So a **ceiling** at 1.3× planned can never cut a flight off before its
closest approach, and ends every long chase within a fraction of a second.

**Registered now, before flying — the PASSAGE WINDOW:** `--breakoff-min-flown-frac 0.8` AND
`--breakoff-force-flown-frac 1.3` (built, default OFF, evaluated every terminal tick on own-state
only, never forces on a missing input). Arms `AE15W`, `S10W` against tonight's `AE15N`, `S10N`
twins, seed 123 then 777. **Adopt iff, per seed:** premature ≤ 1/16; no flight steers > 2 s past
true closest approach (the ceiling should make this 0, so the bar is 0); no flight is cut off
with > 0.5 m of closing still to come (the ceiling's own failure mode — the mirror of
"premature"); median miss per rung not worse than its N twin by > 0.10 m. **NULL:** if the ceiling
cuts off a closing flight, the planned distance is not the bound this analysis says it is (aim
error larger than 15°, or a geometry where the vehicle legitimately overflies) — and the window
is wrong for that regime, which is worth knowing before a real vehicle relies on it.
**Portability:** earned on crossing targets at 4.5–9 m/s with a solved heading and ≤ 15° aim error.

**And the camera still does not earn its place.** With early quits removed on 32 flights, no
rung's median moved by more than its own seed-to-seed spread. The one defect that only the
camera arm could suffer is ~90% gone and the camera-vs-sprint null stands. Tonight's pointing
work (docs/pointing_prereg.md) says why: the camera is almost never shown the target.

### 5e. PASSAGE WINDOW, seed 123 (2026-09-17) — every clause met; seed 777 is flying under the same rule

| rung | cut off / premature (> 0.5 m still to close) | steering > 2 s past closest approach | longest past-closest-approach | median miss, window vs gate-off twin |
|---|---|---|---|---|
| 10 mph (`S10W`) | 0/8 | **0/8** (twin 2/8) | 0.66 s | 0.92 vs 0.84 m |
| 15° aim error (`AE15W`) | 0/8 | **0/8** (twin 4/8) | 0.64 s | 1.41 vs 1.40 m |

12 of the 13 flights that reached a breakoff were ended by the ceiling itself, none before its
closest approach. The window does both jobs the range-increase rule was doing badly, using
nothing but the vehicle's own position and one pre-flight number. Not adopted until seed 777 reads
the same (registered in §5d).

### 5f. PASSAGE WINDOW, seed 777 — every clause met again. ADOPTED (ADR-0101).

| seed | cut off / premature | > 2 s past closest approach (twin) | longest | median miss, window vs twin (10 mph / 15° rung) |
|---|---|---|---|---|
| 123 | 0/16 | 0/16 (6/16) | 0.66 s | 0.92 vs 0.84 / 1.41 vs 1.40 m |
| 777 | 0/16 | 0/16 (4/16) | 0.90 s | 0.79 vs 0.88 / 1.22 vs 1.47 m |

Process note, mine: I edited `run_arm.sh` while the seed-777 `S10W` arm was flying. Bash reads a
running script incrementally, so that arm's wrapper died with a syntax error AFTER its 8 flights
had completed and been written (rc=2; flights and scoring unaffected; only the wrapper's closing
GPU-health print was lost). Do not edit a script a fleet is executing.

---

## 6. RISKS — and where the issue descriptions are wrong

1. **Issue #3 overlooks a measured, in-codebase fix.** Its "a fix needs a different signal:
   own-state kinematics, filtered closing speed, or the LOS sweeping past boresight" reads as
   if a new estimator is required. The red-team already found otherwise (ERROR 3,
   `flight_plan_candidates.md:1113–1123`): the dead-band measurement ruled out ONE
   discriminator (per-step rise magnitude); the absolute-range gate is a different signal,
   already implemented, with a documented value and measured 6/7-vs-2/24 separation. The
   first candidate is a validated flag flip; the issue's signals are the registered
   fallbacks. Taking the issue at face value would have cost a design-and-A/B cycle.
2. **Issue #8's 16/16 is an upper bound, not a result.** Perfect cue, co-altitude, no wind —
   all `given-perfect` inputs. The re-statement must carry that framing everywhere (§4), and
   the conservative logged-tick 12/16 rides alongside the interpolated number permanently.
3. **Interpolation is mildly anticonservative** if 20 Hz sampling aliases real curvature near
   CPA. At ≤ 16 m/s relative speed segments are ≤ 0.8 m and linear-motion error near CPA is
   negligible, but state it, and keep the logged-tick number as the check.
4. **Historical re-score accuracy.** Old CSVs lack attitude, so base_link is reconstructed
   from `gt_cam_*` via measured offsets + `psi_deg` (pitch/roll ignored — worst case during
   a pitched dash ≈ lever × sin(pitch), a few cm). Bound it empirically: the first new-format
   flights carry BOTH exact `gt_intc_*` and the reconstruction; publish the measured error
   bound; if > 0.05 m near CPA, qualify pitched-regime re-scores. Adding attitude columns now
   (ADR-0062's deferred follow-up) closes this class permanently.
5. **The wind Workflow is editing `m4_intercept.py` right now.** #9's fix and #8's m4 touch
   collide with it. Sequence: coordinate with the head session; land #9 as an isolated
   commit either before the workflow's merge or immediately after — never interleaved with
   its wiring agent mid-file. #8's new logic deliberately lives in a new module +
   `rescore_cpa.py` so the m4 diff is a few lines. The fleet flies only after the workflow
   lands AND a byte-identity check proves wind is default-off (else comparability with the
   re-scored dash twins breaks and the fleet repeats — the exact waste this plan prevents).
   And the fleet NEVER flies while workflow agents run: machine load 6.5–7.6 is what VOIDed
   the aim-trim sweep on 2026-07-26.
6. **The Workflow itself is at risk from these defects — tell it.** (a) Any camera arm it
   flies to validate "error correction" before #9/#3 land has a terminal that brakes on
   dropouts and quits early on noise — its A/B could manufacture or erase the effect it is
   measuring. (b) If its vertical error-correction was sized off the published −0.37 m
   offset, half of that number is the camera lever arm (#8): the real vertical gap is
   ~−0.16 m. It may be correcting a number that is 56% measurement artefact.
7. **Verdict re-adjudication discipline.** The old pre-registered bars (camera earns its
   handoff at ≥ 6/8 vs twin; adoption at ≥ 13/16) were chosen before these fixes; they stay
   as-is for the fleet. Re-scoring may flip individual old verdicts — each flip goes through
   the §4 sweep, and no bar is re-chosen after seeing new numbers.
8. **Scope note:** `docs/next.md` currently lists #3 as work-item 1. This plan supersedes that
   ordering (#8 → #9 → #3 → fleet); update `docs/next.md` when the plan is adopted so the two
   surfaces don't contradict.

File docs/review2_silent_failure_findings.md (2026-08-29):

# Review 2 — code-first SILENT-FAILURE audit (2026-07-24)
> **Lens.** The first review (same day) was DOC-first and produced 70 verified gaps, most since fixed.
> This second pass was **CODE-first**, hunting one specific class: *paths that return a confident, plausible,
> WRONG answer with nothing raised* — the shape shared by every defect actually fixed that day. It also
> regression-reviewed the day's 63-file / 13,242-line delta, and had separate agents validate the project's
> error-DETECTION and error-HANDLING methodology.
>
> **125 agents · 111 raw findings · 73 survived adversarial verification** (4 rejected as already-handled; the rest refuted as speculative or wrong).
>
> ⚠️ The run hit a session limit during the final synthesis, so the prose synthesis and 10 of the
> verification agents did not complete. The findings below are the ones that DID pass verification; the
> 10 unverified titles are listed at the end and must be re-verified before being acted on.

## Verified findings, by severity

### BLOCKER

**curve (b)'s truth box is mis-placed off-axis (missing 1/s factor) — a perfect detection scores MISS everywhere but dead centre**  
`scripts/seeker/tripod_score.py:716-733 (x/y/z construction 722-724; gt None -> continue 726-727; band from the wrong gcy 733)` · _correctness_
- **Claim:** tripod_score.curve_b builds the tag's 3-D point as x=(u0-cx)/fx*gr, y=(v0-cy)/fy*gr, z=gr/sqrt(1+a^2+b^2) (tripod_score.py:722-724). x,y are scaled by the RANGE gr while z is scaled by gr/s, so the re-projected truth-box centre lands at u = cx + (u0-cx)*s instead of u0 (s = sqrt(1+tan^2θx+tan^2θy)). Correct is x=a*z, y=b*z. The gt box is therefore displaced radially outward from the principal point by a factor that grows with off-axis angle — on exactly the position-in-frame axis curve (b) exists to measure.
- **Failure mode:** Tripod day: the tag decodes, the NN really does box the target, but every off-boresight frame scores a MISS and every frame-edge frame is dropped from the denominator. Curve (b) prints a confident recall table showing ~100% in the centre band and ~0% top/bottom — which is precisely the 'position-in-frame explains the recall gap' story the project already believes (ADR-0076 add #18k), so the artefact reads as confirmation. No exception, no warning; only 'scored N tag-truthed frames' shrinks.
- **Decision:** Do all four before any tripod session is scored (all are offline, no sim, ~30 min total):

1. FIX the truth box — ~/interceptor-sim/scripts/seeker/tripod_score.py:722-724, replace with:
       a = (u0 - cx) / fx
       b = (v0 - cy) / fy
       z = gr / math.sqrt(1.0 + a * a + b * b)
       x, y = a * z, b * z
   (keeps project_to_bbox's range_m=gr for the box SIZE, which is already right; makes curve_b agree with the IoU-0.965-validated autolabel_from_apriltag.py:82-85 path.)

2. ADD the assertion that would have caught it, in tripod_score.self_test() next to the existing curve_b block (:1278-1297) and mirrored as a pytest in tests/test_tripod_pipeline_join.py: over a grid of (u0,v0) spanning the frame, assert the reprojected truth-box centre lands within 1 px of (u0,v0) out to >=30 deg off-axis, and that project_to_bbox returns non-None for every in-frame tag centre. On the current code this fails at 53.9 px / 43.5% dropped; on the fix it passes at 0.0 px / 0 dropped.

3. STOP THE SILENT DROP — count the `gt is None` continues at :726-727 and the `frame is None` continues at :730-731, and surface both in the note at :739-740 (e.g. "scored N tag-truthed frames; M dropped: K off-frame projection, J unreadable"). A denominator that shrinks without saying so is the whole failure class.

4. PASS THE SESSION CALIB to the hit test at :732 — box_hits_gt(..., fx=fx, fy=fy, cx=cx, cy=cy) — so the sec^2 widening and the principal point come from the real camera, not box_scoring.py:85's sim defaults.

Then attach this to contract task skr-08 (docs/project_state.json:1428-1429) as an explicit precondition: the bench shadow-scoring run only certifies curve (b) if the geometry self-test from (2) is in it — otherwise skr-08 is exactly the green check that hides this.

If a session has ALREADY been scored with the current code, re-run tripod_score.py on the saved session_dir after the fix (frames are stored as PNGs; scoring is fully offline) before any Hailo/markerless go/no-go is acted on. No re-fly needed.

**field_score.py reports the CPA as the minimum over a coarse resample grid — at PX4's default 5 Hz position logging a true 0.30 m KILL scores 2.02 m MISS**  
`scripts/field_score.py:443-449, 483-486, 606, 859-861; self-test pins dt at 723 and 805` · _correctness_
- **Claim:** score_engagement() takes CPA = min(range) over a uniform grid whose step is the FINER log's median sample interval clamped to <=0.2 s (field_score.py:443-449, 483-486). Quantization error is ~v_rel*dt/2, i.e. 1-2 m at a 20 m/s closing speed — 2-4x the 0.5 m lethal radius — so the KILL/MISS verdict is decided by log rate, not by geometry. PX4's default logger records vehicle_global_position (the source field_score PREFERS, field_score.py:212-218) at a 200 ms interval = 5 Hz: ~/PX4-Autopilot/src/modules/logger/logged_topics.cpp:142 `add_topic("vehicle_global_position", 200)`. The file already contains the correct closed form (_analytic_straight_line_cpa, field_score.py:606) but uses it ONLY inside the self-test.
- **Failure mode:** One-shot field day. Interceptor rams the target at a true 0.30 m CPA at ~20 m/s closing. field_score.py is handed the two real logs with no --dt (04_pull_logs.sh:158-160 never passes one) and prints `verdict: MISS, CPA 2.022 m`, writes it to the JSON, and draws it on the plot. Measured on the real code: PX4 5 Hz + ArduPilot 5 Hz -> reported 2.022 m MISS; 5 Hz + 10 Hz -> 1.044 m MISS; 5 Hz + 25 Hz -> 0.500 m (exactly on the threshold); forcing dt=0.01 on the SAME 5 Hz samples recovers 0.300 m KILL. Nothing warns; verdict_uncertain is buried in the JSON and never printed to the console (field_score.py:912-917).
- **Decision:** Five small, immediately actionable edits, all in two files. None touches the sim.

1. (Correctness, exact) Replace the grid argmin with a per-segment closed-form minimum. In scripts/field_score.py, build the piecewise-linear tracks on the UNION of both logs' timestamps, and for each consecutive pair minimize |p_rel(t0) + v_rel*(t-t0)| in closed form with t* clamped to the segment. `_analytic_straight_line_cpa` (field_score.py:606) is already exactly this kernel — it currently only runs inside the self-test. This removes the quantization term entirely, not approximately.

2. (One-line fallback if 1 is too invasive) At field_score.py:446 change `dt = min(max(min(dt_a, dt_b), 0.01), 0.2)` to `dt = min(max(min(dt_a, dt_b) / 20.0, 0.002), 0.05)`. Grid refinement is legitimate here because np.interp already reconstructs the track exactly between samples; the only residual is the chord error of the real curved path, ~a*delta^2/8 ~= 0.05 m at delta=0.2 s and a=10 m/s2. Cost is trivial (a 60 s window at dt=0.002 is 30k points).

3. (Use the data already in the file) At field_score.py:189-190/218, when both `vehicle_global_position` and `vehicle_gps_position` are present, pick the topic with the FINER median sample interval (or at minimum record `median_sample_dt_s` per side in the JSON report — the report currently carries `resample_dt_s` but not the underlying log rates, so a reader cannot audit this).

4. (Kill the console silence) At field_score.py:912-917 print two extra lines: `verdict_uncertain` (already computed at :543) and the quantization bound `v_rel_at_cpa * dt / 2`. That one line is what would have stopped a wrong reading on a one-shot field day. Also annotate the plot's CPA marker with an error bar spanning that bound (:563-567).

5. (Make the self-test able to fail) Add a self-test case with dt=None, hzA=5 / hzB=10, v_rel ~12 m/s, true CPA 0.30 m, radius 0.5, and t0_b deliberately offset by dt/2 so the CPA lands OFF-grid. I verified the existing case2 returns 0.00000 m error with dt=None because its CPA lands exactly on a grid point — a new case without the forced adversarial phase will be blind too.

Housekeeping, same call path, different (already-fixed) defect: scripts/field/04_pull_logs.sh:22 still says "default 1.5 m, its DEFAULT_LETHAL_RADIUS_M"; the default became 0.5 m in commit 92294b0 (field_score.py:120). Correct the comment.

Do NOT frame any of this as rescuing the headline kill claim. Per project_state.json goal.success and field_score.py:527-542, video is the primary evidence and the ~1-3 m GPS inter-receiver bias remains the dominant term. The honest framing: this removes the one error contributor that is fully under our control and is systematically biased in one direction.

**The range-truth chain (the step the whole verdict hangs on) is absent from the protocol, and its auto-sync refuses the day's dominant pass geometry by design**  
`docs/tripod_test_protocol.md §7.1-7.2 (lines 315-373); scripts/seeker/range_truth_join.py:434-438, 508-519; scripts/seeker/tripod_score.py:580` · _process_
- **Claim:** docs/tripod_test_protocol.md §7 never mentions range_truth_join.py, --redecode, --tags-csv, or --stream-fps (grep: zero hits) — the §7.2 command block as written yields UNCERTAIN ('no TRUE ranges'). The real sequence is: tripod_score --redecode (writes a tags.csv with ranges) -> range_truth_join --auto-sync --tags-csv <that file> -> re-score. Separately: auto-sync REFUSES constant-closing-rate geometry as unidentifiable (range_truth_join.py:508-519, proven by its own self-test case 3b) — and the capture matrix (§4.6) is approach-pass-heavy, i.e. mostly that geometry. And if field capture runs without --calib/--tag-size on the Pi, capture-time tags.csv is presence-only (no range_m), so auto-sync finds 0 samples and refuses (range_truth_join.py:434-438).
- **Failure mode:** At 9pm after the drive home, the documented commands return UNCERTAIN; the builder discovers the join tool via the error message, runs auto-sync, and it refuses on most approach passes; if no per-pass sync events were written on the pass cards (because auto-sync was assumed), those passes have no recoverable clock offset and no range truth — permanently.
- **Decision:** Edit docs/tripod_test_protocol.md only (no code change needed; the tools are correct — the doc is the defect). Four concrete edits:

(1) §7.0 NEW "Scoring sequence — run these three, in this order" with the exact commands and the RIGHT interpreter for each:
    a. .venv-seeker/bin/python scripts/seeker/tripod_score.py SESSION --calib calib.json --tag-size 0.35 --redecode --out-dir logs/tripod_score
       (offline re-decode per §6; writes logs/tripod_score/<tag>/tags.csv carrying tag_range_m. It will say GATE UNCERTAIN — expected, this pass exists to produce the tag ranges.)
    b. .venv/bin/python scripts/seeker/range_truth_join.py --session-dir SESSION --bin target.BIN --tripod-lat .. --tripod-lon .. --tripod-alt .. --clock-offset-s <from the §6.1 card>   [add --auto-sync ONLY on the close-crossing sync pass, see (2)]
       NOTE THE INTERPRETER: this one needs .venv (pymavlink); .venv-seeker exits 1 with ModuleNotFoundError.
    c. re-run (a) without --redecode (or with --tags-csv) for the real verdict.

(2) §4.6 flight-plan addendum — "the clock-sync pass": one dedicated LOW, CLOSE crossing pass per battery segment, standoff <= 5 m, flown at FULL speed, target within ~2 m height of the tripod. That is the only geometry in the matrix where --auto-sync can resolve the offset (measured: sens 6.88 m/s -> 0.69 m residual budget at 9 m/s; at 8 m standoff there are ZERO tag-ranged frames inside the 7.1 m decode envelope, and every approach geometry refuses). Reuse that pass's offset via --clock-offset-s for the rest of the segment.

(3) §6.1 — promote the hand sync event from "mark one" to "THE PRIMARY clock source; --auto-sync is a cross-check only, and it will REFUSE on every approach pass by design." Add the one-line arithmetic so it is unambiguous at 9pm: offset_s = t_ULog(sync event) - index.csv:t_wall_unix(that frame index).

(4) §5/§6 — add the field capture command line explicitly, with --calib calib.json --tag-size 0.35, so meta.json carries tag_size_m. Rationale to state in the doc: tripod_score falls back to DEFAULT_TAG_SIZE_M = 0.3 (tripod_score.py:152) against an ADOPTED 0.35 m placard, silently shortening every tag-derived range by 16.7% — which then feeds auto-sync's constant-bias refusal test and curve (a)'s range-accuracy column. (Optional hardening if a code change is wanted: make tripod_score print a WARNING when tag_size came from the default rather than from meta.json/--tag-size.)

Also add range_truth_join.py to project_state.json build_plan P2 task list and to docs/next.md's P0 software roll-up — it is currently invisible to the contract (0 hits), which is exactly the "an update that isn't in the contract didn't happen" failure mode.

**One oversized detector box permanently latches the terminal-coast velocity freeze — the camera is disconnected for the rest of the flight, silently**  
`flight/deploy/seeker_loop.py:235,239,294-316 (+ flight/estimator.py:129-130 rate_cap only on lambda)` · _silent-failure_
- **Claim:** In flight/deploy/seeker_loop.py SeekerGuidance.step, `_frozen_vworld` (line 239) is set once r_hat drops below cfg.terminal_freeze_range_m (3.5 m) and is NEVER cleared: `in_coast = (self._frozen_vworld is not None or r_hat < freeze)` (lines 296-297). Because the range channel is built with NO rate_cap (line 235, unlike the lambda channel), a single 3x-oversized box at 12 m injects rdot_hat ≈ -72 m/s, predict() coasts r_hat through 3.5 m, and the freeze latches for good — even though the target was at a constant 12 m and the detector recovered on the very next frame.
- **Failure mode:** One bloomed/merged/false box (or a nearer object) at any range makes r_hat dip below 3.5 m for one tick. From then on the interceptor flies a constant, frozen NED velocity vector to the end of the engagement, ignoring every subsequent detection. Setpoints keep streaming, all values finite and plausible; the only trace is StepTelemetry.terminal_coast, which real_flight's mission CSV does not log.
- **Decision:** Deploy-path fix, pre-flight, in flight/deploy/ only (do not touch m4's validated mechanization):

1. RESTORE m4 PARITY (the actual divergence): in SeekerGuidance.step, the freeze may only ARM on a tick that carried a fresh correction — mirror m4_intercept.py:3589's `if detected:`. One-line guard at seeker_loop.py:296. Measured: premature latches 18->3 / 45->11 per 400 with legit latches preserved. Also fixes the false parity claim in the class docstring (:227).
2. REQUIRE CORROBORATION: arm the freeze only after N>=2-3 CONSECUTIVE freshly-corrected ticks with r_hat < terminal_freeze_range_m. This is what kills the residual gross-outlier latches that parity alone leaves (69/400 -> expected near the legit-only rate). It is a latch-condition gate, NOT a measurement-rejection gate, so it does not re-enter the graveyarded "phantom range-plausibility gate" family.
3. BROKEN-TRACK ABORT, not a coast: r_hat <= 0 (I measured -2.70 and -6.30 m) or |rdot_hat| above a physical bound (e.g. > 2x v_total_max) is proof the range channel has diverged. That must raise/BREAKOFF via real_flight, never silently select the coast branch.
4. LOG IT: add r_hat_m, rdot_hat_m_s, lambda_dot_deg_s and terminal_coast to real_flight.py's `_CSV_HEADER` (:1111-1113) and `_csv_row` (:1116-1126) — Decision.telemetry is already carried and thrown away. Without this, no post-flight can ever distinguish "coasting" from "guiding".
5. PIN IT: add flight/tests/test_seeker_loop_coast.py — (a) outlier + 2 misses does NOT latch, (b) a genuine monotone close DOES latch at ~3.5 m, (c) the latch survives once armed (deliberate, per ADR-0023: split-freeze measured WORSE in Gazebo, +0.084 m, 2/12 better — do NOT "fix" this by un-freezing v_perp).

EXPLICITLY REJECT the two fixes the claim proposed: (a) porting m4's --terminal-coast-gate / a residual range-plausibility check — the contract graveyards that family ("ADR-0077 gate regressed l2r 81%->25%: a phantom-seeded r_hat makes the gate reject the TRUE closing detections"); (b) a rate_cap on the range channel — m4:2320 has none, so it would diverge from the validated mechanization and would need its own paired-seed A/B before adoption.

**A detection dropout makes the yaw command chase itself: 108 deg of uncommanded yaw in 2 s, guaranteeing the target is never re-acquired**  
`flight/deploy/seeker_loop.py:240,299,328-329; contrast scripts/m4_intercept.py:3760-3777` · _silent-failure_
- **Claim:** seeker_loop.py:328-329 recomputes `yaw_deg = psi_deg(NOW) + degrees(self._last_bearing_rad)` every tick, including ticks with no detection, where `_last_bearing_rad` is the STALE last-seen camera bearing. As the vehicle yaws toward the command, psi grows and the command grows with it — a pure positive-feedback integrator that spins the aircraft at a constant rate for the whole dropout. Simultaneously lambda_hat coasts on its rate-capped rate and v_perp integrates a_cmd to the ±8 m/s clamp. m4_intercept.py does NOT do this: on a no-detection tick it holds last_cmd (m4_intercept.py:3768) or commands yaw = psi (:3775).
- **Failure mode:** Any dropout of ~0.5 s or more (endgame FoV loss is documented as EXPECTED) rotates the body-fixed camera off the target and pins the lateral command at its clamp. The loss becomes self-sustaining. Under real_flight the spin is bounded at 2 s / ~108 deg by FAILSAFE 5; run standalone (the documented on-vehicle command, flight/deploy/README.md:116-121) seeker_loop has no lost-target failsafe at all, so the spin is unbounded.
- **Decision:** Do NOT adopt m4's hold-last-command verbatim (measured worse: beta +30.00 vs -9.25 deg on a 30 deg/s crossing LOS after 1 s dark). Instead, four small, testable changes:

1. LATCH THE ABSOLUTE YAW, COAST IT ON THE ESTIMATED LOS RATE (flight/deploy/seeker_loop.py:327-329). On a detection tick store `self._yaw_cmd_deg = psi_deg + degrees(bearing_h)`; on a no-detection tick do NOT recompute from live psi — advance the stored value by the FROZEN estimate: `self._yaw_cmd_deg += degrees(lambda_dot) * dt`. This kills the transient runaway (the advance rate becomes the ESTIMATED LOS rate, not the un-slewed pointing error) while KEEPING the accidental benefit measured in the crossing case, and it matches the constant-LOS-rate doctrine already built and tested in flight/terminal_coast.py (flight/tests/test_terminal_coast.py:76-98) — which seeker_loop currently does not use at all.

2. MAKE STALENESS VISIBLE AND GATE ON IT. Add `meas_age_s = t - self.lam._last_correction_t` to StepTelemetry, stop integrating v_perp once age > ~2 detector periods (measured: +1.8 m/s of lateral velocity accumulated on a stale rate in 0.5 s), and set a `stale: bool` flag on the tick. Today nothing in the setpoint or the telemetry distinguishes a live command from one running open-loop on a 2 s old bearing.

3. BOUND THE STANDALONE PATH. Either give seeker_loop.run_mavsdk a lost-target abort, or delete the standalone on-vehicle invocation at flight/deploy/README.md:116-121 and point it at real_flight.py (the actual on-vehicle entry point per ADR-0081). Same README block still shows `--weights drone_finetuned_quad_v2.onnx` (line 119) and the config table still lists it as the default (line 129) — stale since c3bd0d9 changed the code default to n-mono; that is the already-fixed blind-model defect surviving in the doc.

4. REGRESSION TEST (the thing that would have caught it): N detections then M dark ticks; assert `abs(yaw_cmd(t) - yaw_cmd(t_last_det)) <= abs(degrees(lambda_dot)) * (t - t_last_det) + eps`. And re-time FAILSAFE 5: with a 20 deg residual bearing and a 45 deg/s yaw loop, the target leaves a +-49.85 deg FoV at 1.55 s, so `engage_lost_target_s = 2.0` (real_flight.py:250) can never fire in time to preserve re-acquisition — either shorten it or make the fix in (1) the thing that keeps the target in frame.

**The deployed terminal guidance has ZERO pytest coverage, and every gate it does have passes with the bearing sign inverted**  
`flight/deploy/seeker_loop.py:197-216 (measurement_from_box), :242-333 (SeekerGuidance.step), :615-627 (the self-test's assertions); flight/tests/test_real_flight.py:594-596 (`guidance=None`); flight/deploy/real_flight.py:1749-1752 (dry-run PASS = states visited)` · _silent-failure_
- **Claim:** `flight/deploy/seeker_loop.py` (SeekerGuidance.step + measurement_from_box) is the ENGAGE terminal that flies the real interceptor (`flight/deploy/real_flight.py:801-803` calls `self.guidance.step(...)`), yet no file in `tests/` or `flight/tests/` imports it. Its only checks are its own `--self-test` (seeker_loop.py:583-639) and real_flight's `--dry-run`/`--sitl-smoke`, all of which assert only finiteness / non-zero speed / state-reachability — never a direction. I injected a full left/right bearing inversion into `measurement_from_box` and the self-test printed 7/7 PASS, rc=0.
- **Failure mode:** A sign/frame regression anywhere in seeker_loop's camera->LOS->NED chain (optical-x convention, derotation call, LOS unit/perp vectors at :301-304, or `yaw_deg = psi + bearing` at :329) yields a perfectly finite, clamped, plausible setpoint that steers the interceptor AWAY from the target. run_tests.sh stays green, the SITL smoke exits 0 (its PASS is `n_sp > 0`), and the failure first appears as a fly-away on a real flight with spinning props.
- **Decision:** Add ~/interceptor-sim/flight/tests/test_seeker_loop.py (pure, no sim, no weights, no MAVSDK — SeekerGuidance is already a pure step function, so this is a ~60-line file that runs in the existing run_tests.sh sweep with no new dependency). Pin DIRECTION and PARITY, in this priority order:

1. Static bearing sign (kills R2 and a measurement_from_box inversion): cam=CameraModel(539.936,539.936,640,480), span 1.0 m, OwnState.level, psi=0. Box centred at u=900 -> assert lambda_hat > 0, sp.v_east > 0, sp.yaw_deg > 0. Box at u=380 -> assert all three < 0. Assert exact mirror symmetry (v_east and yaw negate to <1e-9, v_north identical) — my run gives +/-3.872 and +/-25.71.
2. LOS-rate sign (kills R1 and R4): feed a box walking u = 615 + 20k for 12 ticks at dt=0.05 -> assert lambda_dot_deg_s > 0 AND tel.v_perp > 0 AND sp.v_east > sp.v_north (the lead is East-dominant: my run gives v_perp +8.00, vN +5.34, vE +10.79). Mirror the walk left and assert the negatives.
3. Frame parity (kills R3 and, more importantly, MIRROR DRIFT — the failure mode that already bit once at project_state.json:575): assert seeker_loop's u/p construction reproduces m4_intercept's ENGAGE command for a fixed (lambda, lambda_dot, r_hat, v_perp, psi) tuple. Cheapest honest form: pin the closed-form expectation vN = v_close*cos(lam) + v_perp*(-sin(lam)), vE = v_close*sin(lam) + v_perp*cos(lam), yaw = psi + bearing, citing scripts/m4_intercept.py:3680-3681 and :1443 in the docstring so a future divergence in EITHER file fails the test.
4. Non-zero attitude case (the derotation call is the one line with real frame risk on hardware): same box, own quat at roll 20 deg / pitch -10 deg, assert lambda_hat matches tests/test_bearing_derotation.py's independent matrix reference to 1e-9 — this makes seeker_loop's derotation call, not just flight.geometry's function, sign-anchored.

DO NOT bother wiring `seeker_loop.py --self-test` into run_tests.sh as the fix (the claimant's second proposal): I proved it passes under all four regressions, so adding it buys liveness coverage only. Wire it if you like, but it is not the guard.

Then, same turn: amend docs/project_state.json:575 so "self-test 7/7" is no longer the standing validation evidence for this module — replace/extend with the new test file's pointer, since the current wording certifies a property the check cannot observe.

**The 'no invented fps' fix substitutes a measured number of the WRONG quantity — the $740 gate still turns on an unmeasured rate**  
`~/interceptor-sim/scripts/seeker/tripod_score.py:960-980 (resolve_stream_fps); ~/interceptor-sim/scripts/seeker/pi_capture.py:337-363,446-455 (_fps_stats + live source gate); ~/interceptor-sim/scripts/field/01_camera_live_check.sh:143-145; ~/interceptor-sim/scripts/field/camera_session_summary.py:22-24; ~/interceptor-sim/tests/test_tripod_pipeline_join.py:302-306` · _silent-failure_
- **Claim:** Commit 129ed45 deleted DEFAULT_STREAM_FPS=30.0 and made the tripod money gate demand a 'measured' stream_fps, but the only field-reachable source of that measurement is pi_capture's RECORDER LOOP rate (frame grab + PNG write, with AprilTag decode NOT running), while the gate's burn model `R_streak_burn = (E[T]/stream_fps) x V_closing` needs the ONBOARD DECODE cadence at flight time. tripod_score.resolve_stream_fps rejects only sources containing the substring 'replay', so both the Pi capture rate and a laptop-webcam `--local` rate are accepted as authoritative.
- **Failure mode:** Operator runs the tripod day with `01_camera_live_check.sh --pi` / pi_capture picamera2 (no --decode-tags). meta.json records e.g. stream_fps 30.0 = the rate at which the Pi grabbed and PNG-wrote frames. tripod_score consumes it as the decode/handoff rate, prints `stream fps source: meta.json stream_fps (measured: median inter-frame dt (t_mono_s))`, computes t_go 0.558 s and returns GATE PASS -> BUY the $740 interceptor. The flight loop actually runs 20 Hz and the measured detector cadence is ~14 Hz, at which the same optical data is a FAIL. Symmetrically, a `--local` desk-rehearsal session on the laptop webcam produces an equally 'measured' number from hardware that will never fly.
- **Decision:** Make the gate refuse the wrong quantity instead of relabelling it, and stop pretending one number is two. Five concrete edits, all small, none requiring the sim:

1. pi_capture.py:445-470 — SPLIT the field. Always record `capture_fps` (the recorder-loop rate, what _fps_stats actually measures) and record `decode_fps` ONLY when decode_tags is True. Emit `stream_fps` only from the decode-inclusive case. When decode is off, set stream_fps_source to a string that says so in words: "capture-loop rate — tag decode NOT in the loop; NOT the onboard handoff cadence (protocol §7.3)". Keep the p10 slow-tail for both.

2. tripod_score.py:960-978 — replace the "replay" substring blacklist with a WHITELIST. Accept a meta.json fps only if meta["tag_decode"] is True AND meta["source"] == "picamera2" (the hardware that flies). Otherwise return None with a message that names the quantity actually needed ("sustained end-to-end AprilTag Hz on the Pi 5 at the flying quad_decimate — protocol §7.3 / build_plan P2 task 5") and the one-line fix (`--stream-fps <bench>`). Leave --stream-fps precedence alone. This is the whole silent-failure fix: the v4l2 desk rehearsal and the decode-free field capture both become UNCERTAIN, which is the correct answer.

3. tripod_score.py:924 + gate.json — print the PROVENANCE, not just the source string: which quantity (capture-loop vs decode-inclusive), which backend/hardware, which quad_decimate the bench ran at, and the standing comparison "deployed flight loop = 20 Hz; break-even for this session's R_decode90 = X fps". A reader must be able to see the divisor is a different experiment from the frames.

4. Docs — fix the two places that teach the wrong command: docs/tripod_test_protocol.md:350-353 (add `--stream-fps <§7.3 bench>` to the documented scoring invocation) and tripod_score.py's Usage block (line 98-102). Also correct §8.1:399-402, which still documents the ADR-0079-REJECTED mean-rate burn `(5 / decode_Hz)` while the code gates on run-length E[T] — same gate, doc/code drift, worth folding into the same commit.

5. tests/test_tripod_pipeline_join.py:302-306 — INVERT the locked-in assertion: a {"tag_decode": false} or {"source": "v4l2"} meta must be REFUSED; add the positive case for a picamera2 + decode-inclusive meta. The current test is what would keep this defect green.

Open decision for the builder (one line, not a one-way door): may a `--local`/v4l2 desk-rehearsal session EVER supply the gate's fps? Recommended answer: no — the gate's divisor comes only from the Pi 5 §7.3 bench at the flying quad_decimate, passed explicitly. Log as an addendum to ADR-0082, whose "Honest scope" currently names "achieved Pi capture rate" as the hinge quantity and should be corrected to "sustained onboard decode cadence".

**Ctrl-C at end of a pass silently destroys meta.json (stream_fps, tag_size, exposure verdict) — verified by experiment**  
`scripts/seeker/pi_capture.py:496 (meta write after loop), :432-435 (finally closes CSVs only), :692-693 (Ctrl-C is the documented stop)` · _silent-failure_
- **Claim:** pi_capture.py writes meta.json only AFTER the capture loop completes (scripts/seeker/pi_capture.py:496); a KeyboardInterrupt propagates past the finally block (which only closes CSVs, lines 432-435), so a Ctrl-C-terminated session has frames/ and index.csv but NO meta.json. The script's own help text names Ctrl-C as the way to end a live capture (line 692-693), and ending a pass over ssh with Ctrl-C is the natural field workflow.
- **Failure mode:** Operator starts capture over ssh, target flies the pass, operator hits Ctrl-C. Frames look fine. At home: camera_session_summary exits 2 ('not a pi_capture session'); tripod_score gets meta={} so stream_fps is missing -> money gate returns UNCERTAIN (tripod_score.py:590-597), and tag_size_m falls back to DEFAULT_TAG_SIZE_M=0.3 instead of the 0.35 placard (tripod_score.py:152, 988-989) -> every tag-recovered range silently ~14% short, which also skews auto-sync bias and curve (b) bins. Reproduced today: 3 frames + index.csv written, meta.json absent (scratchpad ctrlc_test.py).
- **Decision:** Fix the ROOT (session finalization is not crash-safe), targeting the SIGTERM variant first since that one is silent:
1. scripts/seeker/pi_capture.py — move the meta build+write (:458-497) into a `finally:` on the frame loop (or a `_write_meta()` helper called from both the normal and exception paths) so SIGINT, SystemExit and normal exit all produce meta.json; add a `"terminated_early": True/False` field so a truncated pass is self-labelling rather than merely incomplete.
2. Same file — flush index.csv (and tags.csv) every N frames (e.g. `idx_f.flush()` every 30 rows, cheap at 30 fps): a hard kill then costs at most one row instead of the measured 25.
3. Same file — install a SIGTERM handler in capture() that raises KeyboardInterrupt/SystemExit, so `systemctl stop` unwinds instead of hard-killing. Cheapest systemd-side belt-and-braces: add `KillSignal=SIGINT` to scripts/pi_setup/capture.service [Service].
4. Docs: docs/tripod_test_protocol.md §6 and docs/field_bringup.md:370 currently give NO per-pass capture command — that vacuum is what makes bare Ctrl-C plausible. Add the exact command (`--n-frames` or `--duration` sized to the pass) plus a per-pass on-Pi check: `test -f SESSION/meta.json && [ "$(tail -n +2 SESSION/index.csv | wc -l)" = "$(ls SESSION/frames | wc -l)" ]`. That second test is the one that catches the silent SIGTERM truncation.
5. Also pass `--tag-size 0.35` at capture time (placard is 0.35 m, docs/placard_sizing.md:194) so meta.json/tags.csv carry it; separately consider making tripod_score.py:988-989 WARN instead of silently taking DEFAULT_TAG_SIZE_M=0.3 when neither --tag-size nor meta supplies one.
6. Do NOT pre-build a meta-recovery script: index.csv already carries t_mono_s/exposure_us/gain, so stream_fps, applied exposure, gain, n_frames and resolution are all reconstructible in ~20 lines if it ever bites.

### HIGH

**The DEFAULT hardware detector weights have no range-calibration sidecar, so range silently falls back to a span constant fitted to the SIM target**  
`flight/deploy/seeker_loop.py:114,214,511-528,920; `ls scripts/seeker/weights/nn_tier/*.calib.json` -> none` · _correctness_
- **Claim:** resolve_span (seeker_loop.py:511-528) tries MARKERLESS_SPAN_M, then <weights>.calib.json, then cfg.target_span_m = 1.0 (line 114). The default weights are scripts/seeker/weights/nn_tier/n-mono.onnx (line 920) and NO calib sidecar exists for any nn_tier model — only the retired sim models have one (drone_finetuned_v2.onnx.calib.json: span_m_eff = 0.9216, fitted on sim_dataset_v2). So on real hardware range = fx*1.0/box_width_px, a constant borrowed from the sim quad, and the run prints 'span=1.000 m (config default)' and proceeds.
- **Failure mode:** Every range-keyed threshold fires at the wrong true distance with no error: compute_v_close throttle at 5.0 m (~1.8 m true), terminal freeze at 3.5 m (~1.3 m true), real_flight breakoff_arm_range_m 4.0 (~1.4 m true) and breakoff_hard_floor_m 0.5 (~0.18 m true — effectively never). r_hat is printed and logged as a confident metric number.
- **Decision:** Three concrete, immediately actionable items (in order):

1. FAIL LOUD INSTEAD OF FALLING BACK. In `flight/deploy/seeker_loop.py:511-528`, make `resolve_span` return the source tag AND have `main()` refuse the LIVE path when the source is "config default": if `args.mavsdk_url and not args.dry_run` (or `--source picamera`) and no env/sidecar span resolved, exit non-zero with "no range calibration for <weights> — run calibrate_range.py or set MARKERLESS_SPAN_M". Desk/dry-run/self-test keep the 1.0 fallback so nothing else breaks. Same treatment for `real_flight.py:1735`, which today never calls `resolve_span` at all — route it through the same resolver and the same refusal, and add `--target-span-m` as the explicit escape hatch.

2. MAKE THE CALIBRATION TOOL USABLE ON REAL DATA BEFORE THE TRIPOD SESSION (it is currently sim-locked in two ways). Add `--fx` / `--intrinsics` to `scripts/seeker/calibrate_range.py` (kill the module-level `FX = 539.936` at :60 as a default-only value) and add a `--gt-csv` mode that reads per-frame ground-truth range from the tripod CSV column (`range_m`) instead of only the `_r<val>` filename stem. Without both, the remediation itself produces a silently wrong constant.

3. SCHEDULE THE FIT AS A build_plan P2 DELIVERABLE. The tripod afternoon (build_plan phases[2]) already shoots tag-truthed range vs NN boxes from the FINAL mount geometry — that session IS the fit set. Add a third deliverable next to "Curve (a) tag decode envelope" and "Curve (b) NN recall vs range": "Curve (c)/artifact: `n-mono.onnx.calib.json` span_m_eff fitted on the same frames", and add a contract constraint that no hardware terminal run uses weights without a sidecar. Sanity-bound the expected answer up front: k should land near 0.30-0.40 m; anything near 1.0 means the fit inherited the sim fx.

One-line honesty note for the ADR when this lands: the current `span=1.000 m` is not merely a display constant — it multiplies Vc into the pro-nav command, so an uncalibrated run flies at an effective N of ~14 rather than the ADR-0011 N=5, and enters the lambda_dot-singular region without the terminal-coast freeze.

**tripod_score.curve_b (the Hailo money-gate curve) scores real imagery with the SIM camera's hardcoded intrinsics, and its scoring body is untested**  
`scripts/seeker/tripod_score.py:669-741 (curve_b), :690, :732; contrast scripts/seeker/nn_tier/eval_n_mono.py:175-186, which for real imagery explicitly passes `fx=box_scoring.FX*s, cx=W/2, cy=H/2`` · _correctness_
- **Claim:** `curve_b` unpacks the session's real calibration at tripod_score.py:690 (`fx, fy, cx, cy, w, h, _dist = calib`) but then calls `box_hits_gt(seeker._infer_boxes(frame), gcx, gcy, gw, gh)` at :732 with NO fx/fy/cx/cy — so box_scoring's sec^2 off-axis widening runs on the sim defaults fx=fy=539.936, cx=640, cy=480 (box_scoring.py:65-66, 84-87, 104-112) regardless of the real lens. For the ordered OV9281 (1280x800, 118 deg HFOV -> fx~=385, cy=400) the effective gt box is under-widened by up to ~1.46x in width and ~1.48x in height off-axis. No test in tests/ or flight/tests/ references curve_b at all; the only coverage is the weights-missing SKIP branch (tripod_score.py:1278-1282).
- **Failure mode:** On the tripod afternoon, curve (b) reports systematically DEPRESSED recall in the off-boresight bands — exactly the range x position-in-frame axis the curve exists to measure — because real, confident, correctly-placed detections fail the size/centre gate. The output is a plausible-looking recall curve with no error, and it is the number that decides the $70 Hailo HAT / the whole markerless phase. Same shape as the frametop 19%-vs-95% scoring artifact the project already got burned by.
- **Decision:** Fix all three in one small patch to scripts/seeker/tripod_score.py curve_b (and it flows to curve_b_multi automatically), then pin it with the first test that ever runs the scoring body. This is desk work, no sim, and it must land BEFORE the tripod afternoon since re-running the curve costs another field day.

1. Fix the gt centre (dominant). Replace tripod_score.py:722-724 with the ray-consistent form:
     tx, ty = (u0 - cx) / fx, (v0 - cy) / fy
     n = math.sqrt(1.0 + tx*tx + ty*ty)
     z = gr / n
     x, y = tx * z, ty * z
   (keep `range_m=gr` in the project_to_bbox call at :725 — the box size is already correct). Assert the round-trip: the returned gcx,gcy must equal u0,v0 to within a pixel.

2. Pass the session's real intrinsics at :732:
     hit = box_hits_gt(seeker._infer_boxes(frame), gcx, gcy, gw, gh,
                       fx=fx, fy=fy, cx=cx, cy=cy)
   and decide `gt_scale` explicitly rather than letting it default to 1.0 — the truth extent here is the REAL target quad's silhouette, whereas box_scoring.TARGET_EXTENT_M=0.52 was mesh-measured on the SIM fpv_quad_enemy. Either measure the real target and set drone_size_m to it (then gt_scale=1.0 is correct and should be stated in a comment), or pass gt_scale_for(...). Leaving it implicit is how frametop defect (1) happened.

3. Count the drops instead of hiding them. Increment `n_skipped_gt` at :726-727 (and `n_skipped_read` at :730-731) and put both in the returned note and in the curve (b) CSV/verdict, so a session where the off-axis third silently vanished is visible rather than reported as clean.

4. Delete the local fallback `def box_hits_gt` at :699-704. It is the pre-fix gate verbatim (no sec^2, no gt_scale, tol=15) and would silently produce the exact pre-2026-07-21 wrong answer if the import ever raises. `from box_scoring import box_hits_gt` directly (box_scoring is pure — no cv2, no onnxruntime — so the import cannot fail for env reasons; importing it via resolution_probe at :697 needlessly drags in cv2 + finetuned_seeker). Let an ImportError be fatal.

5. Add tests/test_curve_b_scoring.py (main .venv, no onnxruntime): monkeypatch a stub seeker whose `_infer_boxes` returns one perfect box at the TRUE tag pixel, build a tiny session with a NON-SIM calib (fx=fy=384.6, cx=640, cy=400, 1280x800), and assert a centred tag AND an off-axis tag at (1000,520) and (640,700) both score HIT, and that no truthed frame is dropped. Pre-fix that test fails on every off-axis case (proved above); post-fix it passes. This is the missing "test the pair, not each script alone" coverage that today's schema breaks already taught.

6. Corollary to decide, not necessarily fix now: make the undistortion frame explicit. Either undistort at :729 to match decode_frames' re-decode path, or record in meta/verdict which pixel frame the u,v came from (pi_capture = raw, --redecode = undistorted) so a 118-deg-lens edge mismatch cannot slip through unlabelled.

**Green can mean 'nothing ran': skips and UNCERTAIN verdicts exit 0**  
`scripts/run_tests.sh:41-42; scripts/seeker/tripod_score.py:1106 (`return 0` regardless of gate verdict)` · _error-handling_
- **Claim:** run_tests.sh's ONNX parity stage passes if the tests skip (missing weights/frames are 'still not a failure' per its own comment), and tripod_score.run() returns 0 unconditionally — even when the verdict is UNCERTAIN.
- **Failure mode:** A moved weights file, a renamed cache dir, or a broken importorskip dependency silently converts the honesty/parity stage into a no-op; any script that ever automates on tripod_score's exit code treats 'could not decide' as success.
- **Decision:** Two targeted fixes, both in files that already exist; do NOT adopt the claim's rationale (it names failure modes the code already catches loudly).

(1) ~/interceptor-sim/scripts/run_tests.sh stage 2 — assert the SUBSTANCE, not the exit code. Before line 43 add a preflight that turns the one real skip trigger into a loud failure:
    .venv-seeker/bin/python -c 'import onnxruntime, cv2' 2>/dev/null || { echo "  FAIL: .venv-seeker lost onnxruntime/cv2 -- ONNX parity would SKIP, not run"; rc=1; }
and correct the comment at :41-42, which is wrong: absent weights raise onnxruntime NoSuchFile (test FAILS) and an absent/renamed capture dir raises FileNotFoundError in the module fixtures (test ERRORs); the only skip path is a missing onnxruntime/cv2 MODULE. Optional belt-and-braces: append `-rs` in that stage and rc=1 if the summary line contains "skipped".

(2) ~/interceptor-sim/scripts/seeker/tripod_score.py:1106 — pre-empt the trap BEFORE the money gate is ever wired into a script: add `--gate` returning 0 on PASS, 1 on FAIL, 2 on UNCERTAIN (keep the current unconditional 0 as the default so no existing manual/doc invocation changes). Note the correction to the claim: FAIL exits 0 too, and that is the more consequential half if this ever gates the ~$740 Tier-2 order — a "FAIL" and a "PASS" being indistinguishable to a wrapper is worse than UNCERTAIN being so.

Generalization worth adopting as a rule (this part of the claim is sound): any gate that can skip or abstain from its own substance must assert a minimum executed count, and must not encode "could not decide" and "passed" in the same exit code.

**autolabel's printed 'tag decode ceiling' is always 100% in negatives mode**  
`scripts/seeker/autolabel_from_apriltag.py:131-156` · _evidence_
- **Claim:** In autolabel_from_apriltag.run(), the --negatives-from-untagged branch increments the SAME `labeled` counter as a real tag decode (autolabel_from_apriltag.py:142) and leaves `untagged` at 0, while the final line prints 100*labeled/len(paths) captioned 'the tag's decode ceiling'.
- **Failure mode:** Running the labeler over target-free footage (its sanctioned negatives mode) prints '[autolabel] tag-label rate 100% (the tag's decode ceiling)' regardless of how many frames actually decoded a tag — a plausible-looking measurement of a quantity that was not measured, on the same tag-decode envelope the money gate turns on.
- **Decision:** One-line-scope fix in scripts/seeker/autolabel_from_apriltag.py run(), strictly better than "suppress the line":

1. Split the counter into `decoded` (:131 branch), `negatives` (:142 branch), `dropped` (:144), and add an `unreadable` counter at :119-120 so the totals always reconcile to len(paths).
2. In negatives mode, DELETE the "decode ceiling" caption (the quantity is not measured there) and instead print: "N negatives written, D frames DECODED a tag (expect 0 on target-free footage), U unreadable, of M frames". Make D>0 print a loud WARNING — that is an operator who pointed --neg at footage containing the tagged target, which today writes positive labels into the negatives dir and is only silently absorbed by split_real_dataset.py:103.
3. In target-present mode keep the ceiling line but compute it as decoded/(decoded+dropped) over READABLE frames, so a corrupt PNG can no longer masquerade as a decode miss.
4. Extend the existing `--self-test` (:160) — which today only checks projection geometry and never touches run() — with a tiny in-memory two-frame case (one composited tag, one blank) asserting that negatives mode reports decoded==0 and does NOT print "decode ceiling". That is the missing test: the current self-test would pass unchanged with the bug in place, which is exactly why it survived.

Cheap, no gate/schema impact, and step 2's D>0 warning is the part that catches a real tripod-day mistake rather than just tidying a print.

**Stale lethal-radius documentation contradicts the corrected 0.5 m default in two places**  
`~/interceptor-sim/scripts/field/04_pull_logs.sh:22-23 and ~/interceptor-sim/scripts/field_score.py:855-858` · _evidence_
- **Claim:** field_score.py's default was corrected to 0.5 m (ram) on 2026-07-24 (field_score.py:120 with rationale), but 04_pull_logs.sh:22-23 still says 'calls KILL/MISS against a lethal radius (default 1.5 m, its DEFAULT_LETHAL_RADIUS_M)' and field_score.py's own --lethal-radius help text (field_score.py:855-858) still reads 'the ADR-0025 net radius; use ~0.5 m for a ram-only claim' while 0.5 IS now the default.
- **Failure mode:** An operator reading either text believes the scorer grades against the 3x-more-forgiving net radius (or passes --lethal-radius 0.5 'to be safe' believing it changes something), and interprets a KILL/MISS verdict against the wrong mechanism - the hand-authored-layer drift shape from today's review, in miniature.
- **Decision:** Two one-line string fixes plus one test that would have caught it. All are trivially safe and need no sim.

1. scripts/field_score.py:856-858 — the help must not restate or mislabel the mechanism. Replace the prose so it reads (with the constant still interpolated):
   help=f"kill classification threshold, metres (default {DEFAULT_LETHAL_RADIUS_M} m = the ADR-0025 kinetic-RAM radius, the parked-net correction of 2026-07-24; pass 1.5 explicitly for a net-class claim). NB the contract's kill stage flags even 0.5 m as a 7-inch number: the ordered 5-inch pair's true contact envelope is ~0.36 m."
   The ADR-0025 mechanism labels are canonically defined in scripts/render_hud.py:120-121 — cite that pair, do not re-derive it.

2. scripts/field/04_pull_logs.sh:22 — delete the restated number entirely (policy rule 7: reference the constant, never restate it). Make line 22 read "...against field_score.py's DEFAULT_LETHAL_RADIUS_M (the ADR-0025 kinetic-ram radius; override with --lethal-radius, which this script forwards)". Note the script already forwards the flag at :160, so the sentence stays true if the constant moves again.

3. THE ACTUAL ROOT-CAUSE FIX — add a 6th self-test case in field_score.py's self_test() that calls the argparse-configured default path (or simply asserts `DEFAULT_LETHAL_RADIUS_M == 0.5` and that the rendered help string does not contain the substring "net"). Every existing case (:723, :760, :805) passes an explicit radius, so the default and its help are currently untestable-by-construction; that is why the 1.5->0.5 flip left contradicting docs behind a green 5/5 PASS. This is the same shape as today's recorder/scorer schema break: two halves each passing their own test, nothing testing the seam.

Optional but cheap: grep for the pattern repo-wide before closing — `grep -rn "DEFAULT_LETHAL_RADIUS_M" scripts/ docs/` currently returns 4 sites; only the two above disagree with the code, and docs/field_bringup.md:334 is already number-free and should stay that way.

**The single highest-value change: one golden contract test per producer→consumer pair, fixture generated by the PRODUCER's own writer**  
`tests/test_tripod_pipeline_join.py:49-52 (the template); missing for mc_batch.sh→mc_analyze.py, coded_dash logs→coded_dash_summary.py, field capture→field_score.py` · _method_
- **Claim:** tests/test_tripod_pipeline_join.py is the correct new check-KIND (it imports the real INDEX_HEADER/TAGS_HEADER and runs the real range_truth_join subprocess end-to-end) — but it exists for only 1 of ~4 file-boundary pairs in the repo.
- **Failure mode:** Without pair coverage, the next schema drift (or a unit change like m vs cm in a shared column) reproduces today's incident: both sides pass their own tests, the pair silently returns empty/garbage, run_tests.sh stays ALL GREEN.
- **Decision:** ADOPT the check-KIND, but re-order it and widen it beyond column names. Concretely, in this order:

P1 (do first — cheapest AND highest-stakes, and it is the pair the claim missed): golden contract test for m4_intercept per-flight CSV -> the engagement/mirage auditors (scripts/coded_dash_summary.py:38-76, scripts/experiments/loft_dive/parse_ab.py is_real/is_det, scripts/audit_per_tick.py). Fixture from the producer's own m4_intercept.py:714-745 CSV_HEADER (importable, unlike mc_batch's heredoc). Assert: (i) every column the auditors read — phase, detected, meas_range, gt_range — is in CSV_HEADER; (ii) a synthetic flight with known real-target ENGAGE ticks classifies CAMERA-GUIDED and one with only phantom ticks classifies dash-only. AND make the tool fail loud: engagement() returning None (unreadable/missing flight CSV) must print a MISSING count and exit non-zero rather than silently counting as camera-guided (coded_dash_summary.py:72) — that default currently turns any pruned-log or fresh-clone run into a 100%-camera-guided claim.

P2: repair + pin the m4-stdout -> mc_batch.sh parse (mc_batch.sh:528-542). Replace the positional regex with an order-independent key=value scan of the `[m4] ...` line, and add a bash-level test that runs record_row's heredoc against a COMMITTED real run-log excerpt (e.g. logs/mc_batch_run_0_20260725T012007Z.log:44) asserting coverage/breakoff_reason/flight_csv_path all non-empty. Add an assert that the header list and row list are the same length. Re-flag docs/decisions.md:1953: the coverage break is not "coded-dash arms", it is every arm since e6be154, and breakoff_reason has been falsified, not merely blank.

P3: extract mc_batch.sh's two heredocs into an importable scripts/mc_row.py (one list -> header + row) — this is the PREREQUISITE that makes the claim's own fixture rule legal for the mc_batch pairs; only then write the mc_batch CSV -> mc_analyze / coded_dash_summary golden test.

P4: wire the self-tests that already exist but never run into scripts/run_tests.sh: `field_score.py --self-test` (field_score.py:707-829) and `range_truth_join.py --self-test`. Cheap, and it closes the claim's pair (2) without new fixtures.

Do NOT accept the claim's stated priority order or its "~4 pairs" scope, and do not accept "fixture from the producer's own writer" as a universal rule until P3 lands.

**The methodology learned the wrong lesson class from its own mirages: most root causes were measurement-layer CODE bugs, but every standing rule hardens EXPERIMENT hygiene**  
`CLAUDE.md 'Standing methodology rules'; docs/decisions.md:1956,1963; docs/project_state.json:437` · _method_
- **Claim:** Of the five-plus retracted 'mirages', at least four root-caused to defects in scoring/audit code, not experiment design: coded_dash_summary counted 'any ENGAGE detection = camera-guided' (decisions.md:1956); resolution_probe.py's hit criterion was backwards, scoring a 376x368 shadow blob as a hit (decisions.md:1963); the up35 tilt test's gt chain was not tilt-aware (decisions.md:1965); approach_recall.py's bins were polluted by grounded-takeoff ticks, manufacturing the '5th mirage' static wall (project_state.json:437). Yet all seven standing rules in CLAUDE.md (sim-time, batch hygiene, statistics-before-verdicts, lab-ranks-Gazebo-decides, worse-than-ideal, honesty boundary, git hygiene) govern how to RUN experiments; none governs how to trust the code that scores them. The paired-control machinery catches the SYMPTOM (a too-good result); the CAUSE was found every single time by someone reading the scorer — an ad-hoc Fable pass, never a standing gate.
- **Failure mode:** A new scorer/gate/audit script ships with a plausible bug; paired seeds and control arms all run through the SAME broken scorer, so the control method is blind to it; the defect surfaces only if a discretionary adversarial code-read happens to look, or (worse) never, if the number is not surprising enough to trigger suspicion.
- **Decision:** Adopt an 8th standing rule in CLAUDE.md — "Instruments are evidence: a scorer bug invalidates every run that passed through it, and controls cannot see it because both arms share the scorer" — but land it as TWO mechanical gates plus one review trigger, so it does not depend on a discretionary spawn:

(1) NO VACUOUS VERDICTS (mechanical, cheapest, highest value). Every verdict-bearing script must return UNCERTAIN/exit!=0 when the number of units actually scored is zero or below a stated floor. Fix the live instance first: ~/interceptor-sim/scripts/audit_per_tick.py:643-660 must not report PASS/exit 0 when n_pass == 0 (proven: pass=0 fail=0 skipped=8 -> "PASS", EXIT=0). Copy the pattern already in scripts/seeker/tripod_score.py:580-591. Add one shared assertion test.

(2) PRODUCER->CONSUMER CONTRACT TEST. Any script that reads another script's artifact gets at least one end-to-end test that runs the REAL producer and feeds its REAL output to the consumer — the tests/test_tripod_pipeline_join.py pattern (353 lines, added today, would have caught both schema breaks and the bin-edge bug). Backlog by risk, verdict-bearing first: audit_per_tick.py, coded_dash_summary.py, antimirage_verdict.py, mc_analyze.py, approach_recall.py, measure_aspect_bias.py, check_jam_mc.py. Add these to run_tests.sh so a silent skip cannot recur (DEEP-T1).

(3) REVIEW TRIGGER, scoped narrowly so it is affordable: a NEW or MODIFIED verdict-bearing script gets an independent adversarial code-read (opus5-worker, not the author session — Fable is safeguard-blocked on this vocabulary) BEFORE its first number enters an ADR or docs/project_state.json. Record the scorer's commit SHA in the ADR alongside the run provenance, so "which instrument produced this number" is answerable months later.

Log as an ADR referencing ADR-0076 add #18g/#18j-fix/#18k, ADR-0082, and commit 129ed45 as the incident base; add the rule text to the contract's constraints (id e.g. "instrument-integrity") next to "anti-mirage", since that constraint explicitly cannot cover non-experiment gates (the tripod money gate has no control arm by construction).

**The gate's stream_fps will measure the capture-loop rate (serial PNG write + tag decode per frame), not the deployed rate — and the $740 verdict flips at ~24 fps**  
`scripts/seeker/pi_capture.py:405-431; scripts/seeker/tripod_score.py:69-88, 960-980` · _method_
- **Claim:** tripod_score refuses to invent an fps (correctly), so the default input is meta.json stream_fps, which pi_capture measures from its own loop timestamps. That loop does cv2.imwrite(PNG 1280x800) + pupil-apriltags decode synchronously per frame (pi_capture.py:405-431, --decode-tags defaults ON at :708-709). On a Pi 5 writing to microSD that plausibly runs 10-20 fps. The verdict break-even is 24.0 fps at the predicted R_decode90=7.10 m (tripod_score.py:69-88).
- **Failure mode:** Field capture honestly records stream_fps=~15; gate returns FAIL on the $740 order — not because the sensor or detector can't sustain the rate, but because the recorder throttled it. Or the builder, seeing this, overrides with the 30 fps paper anchor (--stream-fps 30) and manufactures a PASS — the exact 'invented 30 fps' defect class from this morning's review, reintroduced by hand.
- **Decision:** PRE-REGISTER the gating number, then make the confound un-silent — before the tripod day, no new tool required.

1. PRE-REGISTRATION (docs/tripod_test_protocol.md §7.3 + tripod_score module docstring, one paragraph): the number that gates the $740 order is the SUSTAINED DECODE-ONLY rate on the real Pi 5, at the quad_decimate actually used to score curve (a) — NOT pi_capture's capture-loop rate, and NOT the 30 fps paper anchor. Write it down before any data exists so neither direction can be chosen after seeing the verdict.

2. FIELD-DAY CAPTURE RECIPE (removes the artifact from the recorded number): run the scoring passes with `--out /dev/shm/<session>` (tmpfs, then rsync to SD) and/or `--no-decode-tags` — protocol §6 decodes offline anyway. Then time a decode-only pass over the SAME saved frames on the Pi to produce the number that gates.

3. THREE SMALL CODE EDITS (no new tool):
   a. pi_capture: keep `stream_fps` but add self-describing metadata, e.g. `"stream_fps_kind": "capture_loop"` and `"stream_fps_loop_includes": ["png_write","tag_decode"]` (set from decode_tags + the always-present imwrite), so the number can never be read as a sensor/decode rate.
   b. tripod_score.resolve_stream_fps (:960-980): extend the existing reject/flag mechanism — a meta `stream_fps` of kind `capture_loop` must either be REFUSED (UNCERTAIN naming the missing decode bench, matching the existing no-invented-fps behaviour) or, at minimum, carried into the gate `reason` and the report line at :924 as "CAPTURE-LOOP RATE, includes PNG write — LOWER BOUND on the deployed decode rate".
   c. Either consume `stream_fps_p10_slow_tail` in the gate or delete its "conservative rate for the gate" comment (pi_capture.py:481) — today it is a promise the gate never keeps (0 references).

4. INTERLOCK TO FIX AT THE SAME TIME: add `--quad-decimate` to tripod_score (and pi_capture's detector factory), defaulting to the deployed 2.0 and reporting both 2.0 and 1.0 as protocol §193 asks. Without it, ADR-0082's "qd=1.0 is the planned tripod-day setting" (the branch that is fps-insensitive) is unselectable, and the gate lands on the qd=2.0 / 7.10 m branch that passes only above ~24 fps — exactly where the confounded fps decides the money.

5. DESK BENCH TODAY on the real Pi, once (1) is written: (a) `pi_capture --source picamera2 --duration 60`, record meta stream_fps + p10 tail with decode ON, then repeat with `--no-decode-tags` and with `--out /dev/shm/...`; the spread between those three IS the size of the artifact. (b) decode-only timing over the saved frames at qd 2.0 and 1.0. Expect, from my desktop anchors scaled ~3x: capture-loop ~11-17 fps @qd2 vs decode-only meaningfully higher. If decode-only lands under ~24 fps at qd=2.0, that is a REAL failure of the gate and must be met with qd=1.0 scoring or a bigger placard — not with a hand-typed `--stream-fps 30`.

**ADOPT: a 7-rule error-handling policy this codebase is already half-following**  
`docs section: CLAUDE.md (proposed); exemplars ~/interceptor-sim/scripts/field_score.py:895-906, ~/interceptor-sim/scripts/field/common.sh:11-33, ~/interceptor-sim/scripts/seeker/tripod_score.py:960-980` · _process_
- **Claim:** The repo has one model citizen (field_score.py: helpers raise ValueError naming the file, main() catches once and exits 1, warnings ride in the JSON report) and one good shell contract (scripts/field/common.sh: 0 PASS / 1 FAIL / 2 USAGE / 3 ABSENT). The defects below are all places that deviate from those two existing patterns, so the policy is codification, not invention.
- **Failure mode:** Without a written policy, each new tool re-decides ad hoc; the quiet-degrade pattern (except Exception: pass, `x or DEFAULT`, return-0-regardless) keeps reappearing and produces exactly today's six-defect class: confident wrong output under green checks.
- **Decision:** DO NOT paste 7 rules. Split into two deliverables.

A) THREE CODE FIXES (each independently testable, no sim needed):
  A1. real_flight.py: add an `async def _mode(): async for m in drone.telemetry.flight_mode(): state["offboard"] = (m == FlightMode.OFFBOARD)` coroutine to the `coros` list at :1284, and DELETE the `state["offboard"] = True` write at :1330 (keep the local `offboard_ok` for teardown). Add a staleness guard: if no flight_mode sample has arrived, `offboard_active` stays None, which arm_gate:542 already treats as a fail — so the fix is fail-closed by construction with zero change to :542. Regression test: drive `arm_gate` with offboard_active=None and False and assert `not_offboard` appears in `fails` (real_flight.py:1470 already has a `base = dict(..., offboard_active=True, ...)` fixture to invert).
  A2. finetuned_seeker.py:77-87 and :175-183: replace `except Exception: pass` with a raise. A sidecar that EXISTS but does not parse, or parses to an unrecognized value, must raise ValueError naming the file, the key, and the offending value — never fall through to the stem table or the config default. Non-existence stays the only legal path to "default". Add the 5 rows of my probe as a unit test (they are already written and passing/failing deterministically).
  A3. tripod_score.py:1106: return 0 on PASS, 1 on FAIL, 3 on UNCERTAIN — this is the one tool where the money gate genuinely IS the exit status. Do NOT do this to field_score.py (a measured MISS is a valid result, not a tool failure). Same turn: make the takeoff-wait loops at real_flight.py:1317-1325 and seeker_loop.py:778-785 print `FAIL: not airborne within Ns (rel_alt=...)` and `return 1` instead of falling through.

B) A THREE-RULE CLAUDE.md paragraph (not seven — rules 6 and 7 are dropped/absorbed per the refutations above):
  R1. A default is legal ONLY when its provenance is printed on the same line as the value (the finetuned_seeker.py:184 / seeker_loop.py:997 pattern, already house style). If it can flip a VERDICT, refuse instead and return UNCERTAIN naming the missing measurement (tripod_score.resolve_stream_fps:960 is the exemplar).
  R2. A file that EXISTS but does not parse is an ERROR, never a fallback. `except Exception: pass` around any sidecar/config/meta read is banned outright — this single rule kills findings (2) and (5) and is the exact shape of every schema break fixed today.
  R3. FAIL-CLOSED ZONE = everything between arm and disarm. Any quantity a pre-arm gate checks must be LIVE-SUBSCRIBED, never latched at initialization; if a gate input can be written once and never refreshed, the gate does not exist. Add a mechanical check: for each field of VehicleObs consumed by arm_gate, assert there is a telemetry subscriber writing it.

Cheapest high-value first: A1 (the guard that cannot fire) and A2 (proven by run).

**Today's hardware default-weights fix (blind quad_v2 -> n-mono) is pinned by no test and can silently revert**  
`flight/deploy/seeker_loop.py:919-921; scripts/seeker/tripod_score.py:170-172; no corresponding assertion anywhere under tests/ or flight/tests/` · _regression_
- **Claim:** `grep -rn 'n-mono|DEFAULT_WEIGHTS|quad_v2' tests/ flight/tests/` returns nothing. The three places that choose the real-hardware detector — flight/deploy/seeker_loop.py:919-921, scripts/seeker/tripod_score.py:170-171 — carry the corrected default only as an argparse literal with an explanatory help string. Nothing asserts it.
- **Failure mode:** A merge, a copy-paste from an older sim script, or a well-meant 'restore the deployed model' edit puts quad_v2 back as the hardware default. Every test still passes; the field day then measures a 1.1%-recall detector and reads out as a markerless failure (or a flight acquires nothing) with no signal that the wrong weights were loaded.
- **Decision:** Three parts, in value order — (a) is a live bug fix, not a guard:

(a) FIX THE RUNBOOK FIRST (5 min, highest value). ~/interceptor-sim/flight/deploy/README.md — delete the `--weights .../drone_finetuned_quad_v2.onnx` line from the on-vehicle command (:119) and the desk-replay command (:109) so both inherit the corrected default; change the config-table default at :129 to `weights/nn_tier/n-mono.onnx` and append the reason inline: "real-data model, recall 44.2% / false-fire 4.9% on real held-out imagery vs the sim-trained quad_v2's 1.1% / 88.5% (logs/nn_tier/eval_n-mono_heldout.csv, n=4175); quad_v2 remains selectable for sim replay." Same sweep on docs/detection_tracking_methods.md:190,193 (state table) — mark the pre-fix Finding block at :292-296 as RESOLVED-by-c3bd0d9 rather than editing it away.

(b) ADD THE GUARD, AND MAKE IT COVER THE DOC LAYER — this is where I extend the proposal, because the doc layer is the half that actually broke. One test file, no ONNX/numpy import, pure AST + text:
  1. AST-assert flight/deploy/seeker_loop.py's `--weights` argparse default ends in `nn_tier/n-mono.onnx`;
  2. AST-assert tripod_score.DEFAULT_WEIGHTS ends in `nn_tier/n-mono.onnx` and DEFAULT_WEIGHTS_BAR ends in `drone_finetuned_quad_v2.onnx` (the bar must stay quad_v2 — asserting only the primary lets a swap of the two pass);
  3. assert no hardware-facing runbook (flight/deploy/README.md) contains a `seeker_loop` invocation passing `--weights` with a `drone_finetuned_*` path.
  Header comment names the 44.2%-vs-1.1% measurement and cites commit c3bd0d9 as the defect this pins. Mirror the existing `real_flight.py --audit` AST style.

(c) KILL THE SILENCE AT THE ROOT (2 lines). Extend the `[config]` banner at flight/deploy/seeker_loop.py:996 to print the resolved detector — e.g. `| model=<basename(args.weights)> gray=<resolved modality>` — and stamp the same into the telemetry/log header. Then ANY route to the wrong model (reverted default, stale runbook, operator flag, a future third entry point) is visible on the field-day console and in the log, instead of being reconstructible only from `git log`. Without (c), (b) only pins the two call sites we happen to know about today.

**The contract's published narrative (and docs/next.md) still assert the REFUTED "camera defends imperfect aim" as SETTLED — and the drift check passes green**  
`~/interceptor-sim/docs/project_state.json:6,73-74,185-186,550 · ~/interceptor-sim/docs/dashboard.html:810-811,920-923 · ~/interceptor-sim/docs/next.md:21` · _regression_
- **Claim:** docs/project_state.json's `narrative` block — the §0 story layer that renders as the top of the published dashboard/Artifact — still says "SETTLED: ... the camera defends imperfect aim" (line 73-74) and lists the aim-error test as "IN FLIGHT (the last open sim question)" (line 185-186), while the SAME FILE's `updated_by` (line 6) and the `terminal` stage note (line 550) say that claim is "REFUTED IN SIM and downgraded from settled". docs/next.md:21 carries the same refuted claim as SETTLED CONCLUSION #2. `render_dashboard.py --check` exits 0 and prints "dashboard.html in sync".
- **Failure mode:** Anyone (builder, interviewer, or a fresh session that follows CLAUDE.md's "orient from the narrative first") reads the dashboard's headline story layer and takes away that the camera terminal's value proposition is proven, and that the deciding experiment is still running. The stage-level detail says the opposite. No checker fires: render_dashboard.py --check validates only the embedded-JSON/HTML sync, not whether narrative prose agrees with the stage notes it summarizes — the exact defect class already found once today ("dashboard prose asserted a conclusion the data had reversed").
- **Decision:** Two parts: correct the block, then make the recurrence impossible (the second is the actual fix — this same omission happened 3x today).

A. CORRECT (one edit to ~/interceptor-sim/docs/project_state.json, then render + republish + commit):
1. `narrative.big_lever.headline` — remove "the camera defends imperfect aim" from the SETTLED list; replace with "the camera terminal never earns its handoff in sim (0/8 @5 deg, 3/8 @15 deg)". Update "0.75 m open-loop" → "0.43 m (ADR-0083 +5 deg trim; 0.71 m derived)".
2. `narrative.big_lever.text` — delete "(GL, pending)" (GL flew NULL: 1.44 vs 1.32, 5/8) and drop lever-stack item (2) "the camera defends imperfect aim".
3. `narrative.levers.rows[1]` — category "terminal / the open question" → "terminal — TESTED, REFUTED in sim"; delete the now-false "has NEVER been tested as a controlled pair"; `test` → "DONE 2026-07-24 (AE sweep, paired n=8/cell, seed 123): camera 1.02 vs dash 0.71 (2/8) | 0.58 vs 0.43 (0/8) | 1.51 vs 1.43 (3/8) — never clears the pre-registered 6/8. Binding cause = r2l ADR-0056 aspect bias. BUILD CONSEQUENCE: ENGAGE on the markerless seeker is unjustified by sim evidence — shadow-mode or tag-gated."
4. `narrative.levers.rows[0].test` — fold ADR-0083 (+5 deg trim, 0.71 → 0.43 m, 14/16 pooled, p=0.0021, measured-not-derived, re-measure on hardware).
5. `narrative.program.phases[0].status` + `.what` — replace "closing-speed cost" with the c1baeb9 CONFOUNDED correction and "camera-DRIVEN unconfirmed" with the cdf695b settlement (A-l2r camera-driven confirmed 4/4, −1.18 m; Arm B camera-worse 8/8).
6. docs/next.md:21 SETTLED CONCLUSION #2 — rewrite to the refutation + the build consequence.
7. Add contradiction-ledger entry `narrative-camera-defends-aim-refuted` (verdict CONFIRMED, severity high, status resolved) so the reversal is RECORDED, not silently overwritten — the ledger is the project's stated guard against exactly this.

B. ENFORCE (scripts/render_dashboard.py, ~20 lines, turns the unenforced docstring invariant into a gate):
Give every narrative claim two new required fields — `stage` (the stage id it summarizes) and `as_of` (YYYY-MM-DD) — on `big_lever`, each `levers.rows[]`, and each `program.phases[]`. In `--check`, FAIL when `max(changelog date of the referenced stage) > as_of`: "narrative.big_lever (as_of 2026-07-22) is stale — stage 'terminal' changed 2026-07-24; re-distill or bump as_of." Cheap, mechanical, no prose parsing, and it would have fired on all five stale spots above (GL, AE sweep, ADR-0083, Phase A x2). Optionally also assert `narrative.big_lever.as_of == state.updated` on any commit that touches `updated_by`.

**flight/deploy/README.md still documents and demonstrates the blind quad_v2 model as the on-vehicle weights**  
`flight/deploy/README.md:119,129 vs flight/deploy/seeker_loop.py:920-929` · _safety_
- **Claim:** The README's config table states the `--weights` default is `weights/drone_finetuned_quad_v2.onnx` (line 129) — the code default is nn_tier/n-mono.onnx (seeker_loop.py:920) — and the copy-pasteable 'On the vehicle — live Pi camera, real PX4 OFFBOARD over MAVLink' command explicitly passes `--weights scripts/seeker/weights/drone_finetuned_quad_v2.onnx` (line 119). That is the model measured at AP50 0.0003 / recall 1.1% / false-fire 88.5% on real imagery, which today's fix removed from the code defaults precisely so it could never fly.
- **Failure mode:** The builder follows the runbook, pastes the documented on-vehicle command, and flies the 1.1%-recall model. The loop starts, prints a normal config banner, and simply never detects — indistinguishable from 'the target was too far' or 'the transfer bet failed'.
- **Decision:** Four edits, ordered by durability. The doc fix alone will rot again (it already survived two same-day edits) — the runtime guard is the one that makes it structural.

1. ENFORCE IT IN CODE (the real fix). In flight/deploy/seeker_loop.py main(), after `args = ap.parse_args(argv)`, add a hardware/sim-weights interlock:
   SIM_ONLY_STEMS = {"drone_finetuned", "drone_finetuned_v2", "drone_finetuned_v3", "drone_finetuned_quad", "drone_finetuned_quad_v2", "drone_finetuned_quad_v2_1280", "drone_finetuned_quad_crop", "drone_finetuned_quad_hardened", "drone_finetuned_quad_rebal"}
   If `os.path.splitext(os.path.basename(args.weights))[0]` is in that set AND (args.source == "picamera" OR args.mavsdk_url is not None) → `ap.error(...)` naming the measured numbers (1.1% recall / 88.5% false-fire, logs/nn_tier/eval_s-mono_summary_cmp1.csv) and offering an explicit `--allow-sim-weights-on-hardware` escape hatch. This mirrors the existing P0.4 cam-offset guard pattern (m4 exits 2 on mismatch with an --allow- escape) so it is house-consistent, and it is unit-testable offline in flight/tests/.

2. PRINT THE MODEL WHERE THE VERDICT IS READ. seeker_loop.py:996-1002 — append `| weights={os.path.basename(args.weights)}` to the `[config]` line, so the run log records the detector next to the intrinsics instead of only in a separate `[finetuned]` line that a tail(-n) can miss.
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

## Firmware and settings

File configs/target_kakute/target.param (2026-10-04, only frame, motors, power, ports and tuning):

FRAME_CLASS,1
FRAME_TYPE,1
MOT_PWM_TYPE,6
MOT_BAT_VOLT_MAX,25.2
MOT_BAT_VOLT_MIN,19.8
BATT_MONITOR,4
BATT_VOLT_PIN,10
BATT_CURR_PIN,11
BATT_VOLT_MULT,11.0
BATT_AMP_PERVLT,59.5
BATT_LOW_VOLT,21.6
BATT_CRT_VOLT,19.8
BATT_FS_LOW_ACT,2
BATT_FS_CRT_ACT,1
SERIAL6_PROTOCOL,23
SERIAL6_OPTIONS,0
SERIAL3_PROTOCOL,5
ATC_ANGLE_MAX,35
FLTMODE_CH,12
FLTMODE1,0
FLTMODE2,2
FLTMODE3,5
FLTMODE4,5
FLTMODE5,6
FLTMODE6,3
SERVO1_FUNCTION,36
SERVO2_FUNCTION,33
SERVO3_FUNCTION,34
SERVO4_FUNCTION,35

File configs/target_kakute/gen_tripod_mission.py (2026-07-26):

#!/usr/bin/env python3
"""gen_tripod_mission.py -- emit an ArduPilot/QGC .waypoints AUTO mission for the
tripod field-test pass matrix (docs/tripod_test_protocol.md 4).

WHAT / WHY / WHERE
------------------
WHAT: writes a Mission Planner / QGroundControl "QGC WPL 110" plain-text mission
      file that flies the TARGET quad (Kakute H7, ArduCopter -- see target.param)
      along the tripod test's APPROACH and CROSSING passes, repeatably, in AUTO.
WHY : the protocol wants the range stations GPS-repeatable pass-to-pass so every
      capture bins to the same range (docs/tripod_test_protocol.md 4.1). A scripted
      AUTO mission gives that; hand-flying does not.
WHERE: the emitted file loads via Mission Planner "Plan" > Load WP File, or QGC
       "Plan" > Open. Format ref: https://mavlink.io/en/file_formats/ (QGC WPL 110);
       columns are TAB-separated:
         INDEX  CURRENT  FRAME  COMMAND  P1  P2  P3  P4  X/LAT  Y/LON  Z/ALT  AUTOCONT

GEOMETRY (local ENU about the tripod = HOME)
--------------------------------------------
The camera on the tripod faces --bearing-deg (compass degrees from North). The
target flies IN FRONT of it:
  * APPROACH pass -- straight down the boresight, from --leg-length m out to
    --near-range m, mirroring the sim's head-on regime (protocol 4.2). One pass
    per entry in --lateral-offset (m, +right of the view) so you also sweep
    recall-vs-position-in-frame (protocol 7.2 / ADR-0076 add #18k).
  * CROSSING pass -- a lateral leg at a fixed --standoff m that transects the FOV,
    from -half-width to +half-width (protocol 4.2). With the ADOPTED BEAM-FACING
    placard (docs/placard_mount.md DECISION 1) this is the tag's PRIMARY aspect
    and the block curve (a) actually lives in -- see the geometry note below.
Waypoint speed is set per-pass with DO_CHANGE_SPEED (--speed, and --slow-speed for
the control passes). ENU->lat/lon uses a local equirectangular tangent plane about
HOME (fine at these <100 m ranges).

⛔ THE DEFAULTS WERE SWEPT 2026-07-25 -- THEY USED TO MANUFACTURE A FALSE NO-GO.
This generator shipped --leg-length 30 --near-range 8 --standoff 17, with help
text citing the SUPERSEDED "protocol 4.2 ~15-20". docs/tripod_test_protocol.md
4.1 was corrected on 2026-07-24 (commit dbca8cf) to the contiguous 4..20 m
station grid precisely because the old 8-30 m ladder sits ENTIRELY OUTSIDE the
predicted 7.10 m R_decode90 for the adopted 0.35 m placard: every station would
have returned ~0% decode, curve (a) would read "no range bin sustains >=90%",
and gate_verdict would have returned FAIL -> do not buy the ~$740 interceptor,
for a purely geometric reason. The tool that emits the FLOWN mission was never
swept, so a builder following the corrected protocol would still have flown the
pre-correction geometry. Defaults are now 20 / 4 / 5.5 m, and --self-test
ASSERTS the emitted geometry against the protocol (see check_conformance) so a
future drift FAILS a check instead of flying.

PROTOCOL CONFORMANCE IS ENFORCED, NOT ADVISORY. Emitting a mission whose
geometry cannot answer curve (a) exits 2 with the reason. The legitimate
off-protocol case -- the curve-(b)/NN crossing block at a 15-20 m standoff,
which is NOT envelope-limited the same way -- is available with --off-protocol.

  python3 gen_tripod_mission.py --home-lat 37.8199 --home-lon -122.4786 \
      --bearing-deg 90 --out tripod_mission.waypoints
  # the curve-(b) NN crossing block (deliberately outside the tag envelope):
  python3 gen_tripod_mission.py --home-lat .. --home-lon .. --passes crossing \\
      --standoff 17 --off-protocol --out nn_crossing.waypoints
  python3 gen_tripod_mission.py --self-test     # offline, no hardware, exits 0/1
"""
from __future__ import annotations

import argparse
import io
import math
import os
import sys
import tempfile
from dataclasses import dataclass

# ---- QGC WPL 110 constants -------------------------------------------------
WPL_HEADER = "QGC WPL 110"
FRAME_GLOBAL = 0            # MAV_FRAME_GLOBAL (abs alt) -- used for the HOME row
FRAME_REL_ALT = 3          # MAV_FRAME_GLOBAL_RELATIVE_ALT -- alt is AGL above home
CMD_WAYPOINT = 16          # MAV_CMD_NAV_WAYPOINT
CMD_TAKEOFF = 22           # MAV_CMD_NAV_TAKEOFF
CMD_RTL = 20               # MAV_CMD_NAV_RETURN_TO_LAUNCH
CMD_CHANGE_SPEED = 178     # MAV_CMD_DO_CHANGE_SPEED
SPEED_TYPE_GROUND = 1      # DO_CHANGE_SPEED param1: 1 = ground speed
N_COLS = 12                # QGC WPL 110 has exactly 12 tab-separated columns

# metres per degree latitude (WGS84 mean); longitude scaled by cos(lat)
M_PER_DEG_LAT = 111320.0

PLACEHOLDER_LATLON = (0.0, 0.0)

# ---- PROTOCOL GEOMETRY (docs/tripod_test_protocol.md, corrected 2026-07-24) --
# Every constant below is the PROTOCOL's number, not a tunable. The self-test
# asserts the EMITTED mission against them, so a default that drifts away from
# the protocol fails a check instead of flying.
#
# 4.1 range stations, corrected because the predicted R_decode90 for the adopted
# 0.35 m placard is 7.10 m realistic (5.98 m conservative, 8.97 m full-res --
# docs/placard_sizing.md 5). The 4/6/10 m near stations are "the money stations".
PROTOCOL_STATIONS_M = (4.0, 6.0, 8.0, 10.0, 12.0, 14.0, 16.0, 18.0, 20.0)
# 4.1 verbatim: "The 4/6/10 m near stations are the money stations -- they are
# where the tag is predicted to actually decode."
PROTOCOL_MONEY_STATIONS_M = (4.0, 6.0, 10.0)
# 4.1 "Bin curve (a) in 2 m bins ... --range-bin 2 --max-range 20". The grid must
# be CONTIGUOUS on this bin: scripts/seeker/tripod_score.py r90_walk STEPS one
# bin at a time and STOPS at the first absent/underpopulated bin, returning
# UNCERTAIN (never PASS). A hole in the flown grid = a wasted field day.
PROTOCOL_RANGE_BIN_M = 2.0
# 4.2 "Use a ~5-6 m standoff for the dedicated tag-envelope crossing block"
# (inside the predicted decode envelope). With the beam-facing placard
# (docs/placard_mount.md DECISION 1) this block IS curve (a).
PROTOCOL_TAG_CROSS_STANDOFF_M = (5.0, 6.0)
# 4.2 "the old ~15-20 m standoff is retained ONLY for the NN/curve-(b) crossing
# passes, where detection is not envelope-limited the same way." Reaching it
# requires --off-protocol, so it can never be flown for curve (a) by accident.
PROTOCOL_NN_CROSS_STANDOFF_M = (15.0, 20.0)
# 4.4 "pushing toward the eventual >=9 m/s engagement regime"; 4.4 control pass
# "~2-4 m/s".
PROTOCOL_FULL_SPEED_MIN_MPS = 9.0
PROTOCOL_SLOW_SPEED_BAND_MPS = (2.0, 4.0)
# docs/placard_mount.md 8, HARD limit: at the 90 deg (nose-on) placard index the
# panel is normal to the flow -- 11.8 N of drag, ANGLE_MAX reached at 5.83 m/s,
# and the trim pitch itself throws the tag outside the incidence cone. The
# nose-on block is the ONLY source of approach-aspect decodes (and therefore of
# autolabel_from_apriltag.py's approach-aspect training frames), so the tool
# refuses to emit one above the cap.
PROTOCOL_NOSE_ON_INDEX_DEG = 90.0
PROTOCOL_NOSE_ON_MAX_MPS = 4.0

# Emitted-geometry tolerance (m). The equirectangular round-trip is exact to
# <1 mm at these ranges; this only absorbs float formatting in the .waypoints
# file (6 decimal places of latitude ~ 0.1 m).
GEOM_TOL_M = 0.25


@dataclass
class MissionItem:
    seq: int
    current: int
    frame: int
    command: int
    p1: float
    p2: float
    p3: float
    p4: float
    x: float          # latitude (deg) for NAV cmds, else 0
    y: float          # longitude (deg) for NAV cmds, else 0
    z: float          # altitude (m)
    autocontinue: int
    # WHICH PASS THIS WAYPOINT BELONGS TO, tagged at CONSTRUCTION ("approach" /
    # "crossing" / "" for HOME/TAKEOFF/RTL). NOT serialized -- QGC WPL 110 has
    # exactly 12 columns and the round-trip must stay byte-stable; the tag is
    # carried alongside the file into waypoint_geometry.
    # WHY IT EXISTS (2026-07-26 BLOCKER): check_conformance used to infer the
    # pass type from |lateral_m| > 0.5*bin_m, so the tool's OWN documented
    # offset sweep (--lateral-offset=-5,0,5, protocol 7.2) had its +/-5 m
    # APPROACH endpoints read as CROSSING waypoints at standoffs 4 and 20 m and
    # was REFUSED -- the README section 9 build-day command exited 2 and wrote
    # nothing, blaming a crossing standoff that was correctly 5.5 m. Any
    # threshold on lateral offset has this failure; the pass type is a property
    # of how the waypoint was BUILT, so that is where it is recorded.
    pass_type: str = ""

    def to_line(self) -> str:
        # Mission Planner writes ints for seq/current/frame/cmd/autocont and
        # high-precision floats for the rest. Match that so QGC/MP parse it.
        return "\t".join([
            str(self.seq), str(self.current), str(self.frame), str(self.command),
            _fmt(self.p1), _fmt(self.p2), _fmt(self.p3), _fmt(self.p4),
            _fmt(self.x, 8), _fmt(self.y, 8), _fmt(self.z, 6),
            str(self.autocontinue),
        ])


def _fmt(v: float, prec: int = 6) -> str:
    return f"{float(v):.{prec}f}"


# ---- local ENU (metres) -> lat/lon (deg) -----------------------------------
def enu_to_latlon(home_lat: float, home_lon: float, east_m: float, north_m: float):
    dlat = north_m / M_PER_DEG_LAT
    dlon = east_m / (M_PER_DEG_LAT * math.cos(math.radians(home_lat)))
    return home_lat + dlat, home_lon + dlon


def view_and_right(bearing_deg: float):
    """Unit ENU vectors for the camera VIEW direction (compass bearing) and the
    RIGHT direction (bearing + 90 deg). Returns ((vE,vN),(rE,rN))."""
    b = math.radians(bearing_deg)
    view = (math.sin(b), math.cos(b))               # bearing: E=sin, N=cos
    right = (math.sin(b + math.pi / 2), math.cos(b + math.pi / 2))
    return view, right


def _front_point(home_lat, home_lon, bearing_deg, range_m, lateral_m):
    """A point range_m in front of the camera, offset lateral_m to the right."""
    (vE, vN), (rE, rN) = view_and_right(bearing_deg)
    east = range_m * vE + lateral_m * rE
    north = range_m * vN + lateral_m * rN
    return enu_to_latlon(home_lat, home_lon, east, north)


def latlon_to_enu(home_lat: float, home_lon: float, lat: float, lon: float):
    """Inverse of enu_to_latlon (same tangent plane). Used to read the EMITTED
    mission's geometry back out of the .waypoints file, so conformance is
    checked against what will actually be FLOWN, not against the arguments that
    were meant to produce it."""
    north = (lat - home_lat) * M_PER_DEG_LAT
    east = (lon - home_lon) * (M_PER_DEG_LAT * math.cos(math.radians(home_lat)))
    return east, north


def waypoint_geometry(items, home_lat, home_lon, bearing_deg, pass_types=None):
    """Every NAV waypoint (excluding HOME/seq 0) as a dict with the three numbers
    the protocol is written in:

      along_m    distance along the camera boresight (= the RANGE STATION for an
                 approach waypoint, and the STANDOFF for a crossing waypoint)
      lateral_m  offset +right of the view
      range_m    slant range from the tripod = hypot(along, lateral)
      pass       "approach" / "crossing" / "" -- from `pass_types` (a {seq: type}
                 map taken off the BUILT MissionItems), never inferred from the
                 geometry (see MissionItem.pass_type for why).

    This is the read-back the self-test asserts on: the NUMBERS still come out of
    the emitted file, so a geometry drift is still caught against what will be
    flown; only the LABEL comes from construction. `alt` is deliberately not
    folded into range_m: the protocol flies the target CO-ALTITUDE with the
    camera (3.1), so the mission's AGL alt is the camera's height, not a
    vertical separation."""
    (vE, vN), (rE, rN) = view_and_right(bearing_deg)
    out = []
    for it in items:
        if it.command != CMD_WAYPOINT or it.seq == 0:
            continue
        e, n = latlon_to_enu(home_lat, home_lon, it.x, it.y)
        along = e * vE + n * vN
        lateral = e * rE + n * rN
        ptype = (it.pass_type if pass_types is None
                 else pass_types.get(it.seq, ""))
        out.append({"seq": it.seq, "along_m": along, "lateral_m": lateral,
                    "range_m": math.hypot(along, lateral), "pass": ptype})
    return out


def pass_type_map(items):
    """{seq: pass_type} off the BUILT mission items, to be carried into
    waypoint_geometry alongside the parsed file."""
    return {it.seq: it.pass_type for it in items}


def check_conformance(geom, *, passes, speed, slow_speed, placard_index_deg,
                      stations=PROTOCOL_STATIONS_M, bin_m=PROTOCOL_RANGE_BIN_M,
                      tag_standoff=PROTOCOL_TAG_CROSS_STANDOFF_M):
    """Does this EMITTED geometry match docs/tripod_test_protocol.md 4?

    Returns (violations, warnings) -- both lists of strings. A violation means
    the mission cannot answer curve (a) (the ~$740 gate); main() exits 2 on one
    unless --off-protocol is given. This is the check that had TEETH missing:
    the old --self-test verified mission STRUCTURE and round-trip, so the
    pre-correction 8/17/30 m defaults passed it green.

    Checked against the EMITTED waypoints (waypoint_geometry), not the args --
    with ONE exception, deliberate: which pass a waypoint belongs to is read off
    its construction tag, not guessed from its lateral offset (see
    MissionItem.pass_type; the guess REFUSED the tool's own documented offset
    sweep)."""
    v, w = [], []
    lo_station, hi_station = float(min(stations)), float(max(stations))

    appr = [g for g in geom if g["pass"] == "approach"]
    cross = [g for g in geom if g["pass"] == "crossing"]

    if "approach" in passes:
        # THE STATION GRID IS A PROPERTY OF THE BORESIGHT LEG. tripod_score bins
        # on TRUE SLANT RANGE, so an offset leg genuinely never reaches the 4 m
        # station (hypot(4,5) = 6.4 m) -- evaluating near/far/contiguity over the
        # UNION of all approach waypoints would therefore false-refuse an
        # offsets-only mission for a real geometric reason stated as the wrong
        # one. The offset legs answer protocol 7.2 (recall vs position in
        # frame); curve (a)'s range grid is answered by the on-boresight leg, so
        # that is the leg the grid checks run on -- and one must exist.
        boresight = [g for g in appr if abs(g["lateral_m"]) <= 0.5 * bin_m]
        if not appr:
            v.append("approach pass requested but NO approach waypoint was "
                     "emitted")
        elif not boresight:
            v.append(
                f"approach passes were emitted but NONE is ON BORESIGHT "
                f"(lateral offsets "
                f"{sorted({round(g['lateral_m'], 1) for g in appr})} m). "
                f"Protocol 4.1's contiguous {lo_station:.0f}-{hi_station:.0f} m "
                f"station grid is flown down the boresight -- an offset leg's "
                f"slant range never reaches the near stations, so this mission "
                f"cannot answer curve (a). Include 0 in --lateral-offset")
        else:
            appr = boresight
            near = min(g["range_m"] for g in appr)
            far = max(g["range_m"] for g in appr)
            if near > lo_station + GEOM_TOL_M:
                v.append(
                    f"approach NEAR end is {near:.1f} m but protocol 4.1's "
                    f"nearest station is {lo_station:.0f} m -- the "
                    f"{'/'.join(f'{s:.0f}' for s in PROTOCOL_MONEY_STATIONS_M)} m "
                    f"MONEY STATIONS (where the tag is predicted to actually decode, "
                    f"R_decode90 ~7.10 m) would never be flown")
            if far < hi_station - GEOM_TOL_M:
                v.append(
                    f"approach FAR end is {far:.1f} m but protocol 4.1 wants the "
                    f"grid out to {hi_station:.0f} m -- without it the >=90% walk "
                    f"ends on `end_of_data`, which is bounded by what was never "
                    f"shot and returns UNCERTAIN, never PASS")
            # Contiguity on the scorer's own 2 m bin: a continuous inbound leg
            # fills every bin between its endpoints, so the test is that the leg
            # SPANS the whole station grid.
            n_bins = int(round((hi_station - lo_station) / bin_m))
            missing = [lo_station + k * bin_m for k in range(n_bins)
                       if not (near <= lo_station + k * bin_m + GEOM_TOL_M
                               and far >= lo_station + (k + 1) * bin_m - GEOM_TOL_M)]
            if missing:
                v.append(
                    f"the approach leg does not cover the contiguous {bin_m:.0f} m "
                    f"bins {[f'{m:.0f}' for m in missing]} -- r90_walk STOPS at the "
                    f"first absent bin (tripod_score.r90_walk) and the verdict is "
                    f"UNCERTAIN")

    if "crossing" in passes:
        if not cross:
            v.append("crossing pass requested but NO off-boresight waypoint was "
                     "emitted")
        else:
            stand = sorted({round(g["along_m"], 3) for g in cross})
            lo_s, hi_s = tag_standoff
            bad = [s for s in stand if not (lo_s - GEOM_TOL_M <= s <= hi_s + GEOM_TOL_M)]
            if bad:
                v.append(
                    f"crossing standoff {['%.1f' % s for s in bad]} m is outside "
                    f"protocol 4.2's {lo_s:.0f}-{hi_s:.0f} m TAG-ENVELOPE band. "
                    f"The adopted placard is BEAM-FACING (placard_mount DECISION 1), "
                    f"so crossing is the tag's PRIMARY aspect and this block IS "
                    f"curve (a) -- flown at the old 15-20 m NN standoff it sits "
                    f"outside the 7.10 m envelope and returns structural zeros. "
                    f"Use --off-protocol only for the curve-(b)/NN crossing block")

    if speed < PROTOCOL_FULL_SPEED_MIN_MPS:
        w.append(f"--speed {speed:.1f} m/s is below protocol 4.4's >=9 m/s "
                 f"full-speed regime -- the motion-blur read is the one thing "
                 f"this day can measure that sim cannot")
    lo_sl, hi_sl = PROTOCOL_SLOW_SPEED_BAND_MPS
    if not (lo_sl <= slow_speed <= hi_sl):
        w.append(f"--slow-speed {slow_speed:.1f} m/s is outside protocol 4.4's "
                 f"{lo_sl:.0f}-{hi_sl:.0f} m/s control band")

    if placard_index_deg is not None:
        idx = abs(float(placard_index_deg))
        if idx >= PROTOCOL_NOSE_ON_INDEX_DEG - 1e-9 and speed > PROTOCOL_NOSE_ON_MAX_MPS:
            v.append(
                f"--placard-index-deg {placard_index_deg:.0f} (nose-on) at "
                f"{speed:.1f} m/s breaks the HARD <= {PROTOCOL_NOSE_ON_MAX_MPS:.0f} m/s "
                f"cap in docs/placard_mount.md 8: nose-on the 450 mm panel makes "
                f"11.8 N of drag, ANGLE_MAX is reached at 5.83 m/s, and the trim "
                f"pitch throws the tag outside its own incidence cone")
        if 1e-9 < idx < PROTOCOL_NOSE_ON_INDEX_DEG - 1e-9 and "approach" in passes:
            w.append(f"--placard-index-deg {placard_index_deg:.0f} with approach "
                     f"passes: only the 90 deg index yields approach-aspect "
                     f"decodes at all (placard_mount 3.6)")
    return v, w
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

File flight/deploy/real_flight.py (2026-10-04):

#!/usr/bin/env python3
"""flight/deploy/real_flight.py -- the REAL interceptor's ONBOARD FLIGHT STATE MACHINE.

    *** SKELETON FOR BUILDER REVIEW -- NOT FLIGHT-READY. ***
    Every constant marked TODO-BUILDER below is a GUESS or a sim-derived number
    that must be re-measured on the physical aircraft before props ever spin.
    The SITL-testable half (state machine, guards, failsafes, handoff) is real
    and unit-tested; the hardware half (RC channel map, PWM endpoints, link
    timeout, geofence, battery budget) is deliberately unfinished.

WHAT THIS IS
------------
`flight/deploy/seeker_loop.py` implements the TERMINAL seeker only -- on the
vehicle path it deliberately does not arm, take off, or land ("props-spinning
autonomy is the dash's job"). THIS file is that missing dash: the launch/standby
logic and the coded open-loop dash that DELIVERS the airborne interceptor to the
terminal, per `docs/launch_mechanism_plan.md` Sec 5 (the plan's one real build
item, L1).

    ground takeoff  ->  STANDBY   armed hover at the loft altitude, holding the
                                  commanded aim yaw, streaming hold setpoints so
                                  PX4 stays in OFFBOARD
                          | human TRIGGER (ELRS aux channel, arm/kill class --
                          | carries NO target information; Sec 4)
                          v
                        CODED_DASH open-loop NED velocity at the pre-flight
                                  collision-lead heading, accel ramp + loft dive
                                  from flight.guidance. NO datalink, NO cue, NO gt.
                          | 5 consecutive fresh camera detections (the streak IS
                          | the handoff -- mirrors scripts/m4_intercept.py)
                          v
                        ENGAGE    seeker_loop.SeekerGuidance -- the SAME camera-only
                                  pro-nav terminal the sim validates (composed, not
                                  re-implemented)
                          | past-CPA / timeout / target-lost
                          v
                        BREAKOFF -> SAFE (hover, land requested)

Every failsafe is a GUARDED, LOGGED transition into SAFE. There is no path that
"continues blindly".

POST-GO OFFBOARD LOSS (FAILSAFE 7, builder decision #22): after the GO edge the
RF link may die freely (that is the whole no-datalink claim), but the OFFBOARD
CONTROL PATH may not. If PX4 leaves OFFBOARD -- or the flight-mode sample that
claims it is IN OFFBOARD goes stale, i.e. we no longer KNOW -- during
CODED_DASH/ENGAGE/BREAKOFF, the machine goes SAFE. Two reasons, both about
props-on hazard: (1) while PX4 is out of OFFBOARD our setpoints are not being
flown, so every guard downstream of them (the dash bound, breakoff, the terminal)
is scoring a flight that is not happening; (2) SAFE is ABSORBING, so when the
pilot hands OFFBOARD back the vehicle receives a ZERO-velocity hold + a land
request -- NOT a live, half-ramped dash command that would fire the moment
control returns. Link-loss and OFFBOARD-loss are deliberately opposite policies:
one is expected and ignored, the other is a control-path failure and aborts.

COMPOSITION (this file adds a state machine and NOTHING else)
------------------------------------------------------------
  * the terminal            -> flight.deploy.seeker_loop.SeekerGuidance (imported)
  * the dash aim            -> flight.guidance.collision_lead_heading_accel (ADR-0080)
  * the dash speed ramp     -> flight.guidance.dash_forward_speed
  * the loft-then-dive ref  -> flight.guidance.dash_loft_alt_ref
  * the alt trim + AGL floor -> flight.guidance.apply_alt_ref_trim
  * the dash dead-reckoned distance -> flight.guidance.dash_ramp_distance
  * the MAVSDK connect/own-state/OFFBOARD pattern -> mirrors seeker_loop.run_mavsdk
    (including the connect() timeout + _kill_server trap measured 2026-07-24)

HONESTY / NO-CHEAT AUDIT (CLAUDE.md honesty boundary; re-earned here because the
dash is a NEW command path)
--------------------------------------------------------------------------------
The state machine's ONLY inputs are:
  1. CAMERA PIXELS  -- and only in ENGAGE, through the seeker (a detection box,
     plus its implied range, which is what the handoff streak counts).
  2. OWN-STATE EKF  -- attitude quaternion, yaw, relative altitude, armed/offboard
     status, as MAVSDK reports them. Actuation (arm/takeoff/land) is not an input.
  3. PRE-FLIGHT CONSTANTS -- dash heading, standby altitude, standby yaw, dash
     speed/accel, trigger channel + thresholds. Computed or entered BEFORE launch.
  4. ONE BIT over the RF link -- the GO edge. It is arm/kill class: a single edge
     carrying zero target information, and the link may be killed immediately
     after with no effect on the intercept (constraint `no-datalink`; the
     link-denied flight arm L11 is the deliverable that PROVES it).

There is no ground truth on real hardware to read and none is read here: no
identifier in this module is a ground-truth symbol, and `--audit` proves it from
the syntax tree (not the text) along with the LATCH-ONCE property below.

LATCH-ONCE (docs/launch_mechanism_plan.md L2 / ADR-lite #5 "nothing may read a
sensor after the GO edge"): the dash heading lives in a `LatchOnce` cell that
RAISES on a second write, and `--audit` proves the source contains exactly ONE
`.set(` call site for it -- the GO edge. So "the dash cannot be re-steered
mid-flight" is machine-checked, not promised.

SIM-CLOCK vs WALL-CLOCK: there is no sim clock on the vehicle. Every duration
here is `time.monotonic()` seconds -- monotonic, NEVER `time.time()` (a GPS time
sync can step the wall clock mid-flight and would corrupt the dash ramp). The
state machine takes `t` from the caller, so tests inject a fake clock.

RUN IT
------
  # pure-logic self-test + honesty audit (no MAVSDK, no sim, no camera)
  .venv/bin/python -m flight.deploy.real_flight --self-test
  .venv/bin/python -m flight.deploy.real_flight --audit

  # offline dry-run: fake vehicle, scripted trigger, PRINTS every transition
  .venv/bin/python -m flight.deploy.real_flight --dry-run

  # against a live PX4 SITL (the head runs this; needs a booted sim)
  .venv/bin/python -m flight.deploy.real_flight --sitl-smoke \
      --mavsdk-url udpin://0.0.0.0:14540

DEPS: pure stdlib + numpy (via seeker_loop). `mavsdk` is a GUARDED import used
only by the live driver, so every offline path runs on this x86 desk.
"""
from __future__ import annotations

import argparse
import ast
import json
import math
import os
import sys
import time
from dataclasses import dataclass, field, replace
from typing import Callable, List, Optional, Sequence, Tuple

_REPO_ROOT = os.path.dirname(os.path.dirname(os.path.dirname(os.path.abspath(__file__))))
if _REPO_ROOT not in sys.path:
    sys.path.insert(0, _REPO_ROOT)
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

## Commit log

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2026-07-04 M2: AprilTag detection — live detection vs ground truth, gate passing
    - worlds/apriltag.sdf + models/apriltag_target/: tag36h11 id0 on a 0.625 m
    plane at (5, 0, 0.5) facing -X; emissive_map material so the tag stays
    legible at range under default.sdf's fixed sun (ADR-0007)
    - scripts/m2_detect.py: pupil-apriltags on live gz-transport frames,
    pose error vs /world/apriltag/pose/info ground truth (ADR-0006 documents
    the camera_link transform-chain gotcha)
    - Gate: detection_rate 1.000, mean err_norm 0.0861 m (bar <=0.25 m) at
    ~4.9 m range; verifier-confirmed
    - camera_intrinsics.json: measured fx=fy~539.94, cx=640, cy=480
    [apriltag.sdf, model.sdf]
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2026-07-06 Audit corrections: lab-vs-Gazebo qualifiers, stale citations, byte-identity scope, forensics preserved
    Applied Fable audit findings (D, E/F, G/H) as inline corrections — no conclusion
    reversed, but several claims re-scoped to match their evidence tier:
    - kill_mechanism.md + decisions.md: net's ~40-75% Pk tagged LAB-not-Gazebo (the
    one component later Gazebo-tested landed ~1/5 the lab effect).
    - decisions.md: ADR-0014 'byte-identical' scoped to stdout+prior-column values (an
    additive terminal_coverage CSV column landed at 90ed502); ADR-0023-addendum BC
    'HURTS' softened (t~2.60, p~0.025 uncorrected, borderline); ADR-0018 fusion verdict
    flagged as run under the uncorrected steep sigma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
    [per_flight_summary.csv]
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2026-07-06 Tier-2 pinned (ADR-0024 addendum): 60deg camera shadow SDF + decisions from 3 parallel studies
    Offline prep for the acquisition-range build, from three concurrent design studies:
    - models/mono_cam/{model.sdf,model.config}: repo-local shadow of PX4's camera,
    ONLY horizontal_fov 1.74->1.0472 (99.7->60deg). Resolves via model://mono_cam +
    GZ_SIM_RESOURCE_PATH precedence (ADR-0005 precedent); PX4 tree untouched (ADR-0001).
    - ADR-0024 addendum: FOV=60deg, HANDOFF_RANGE 10->12, streak-min A/B plan (score on
    Pk not conditional-miss), and L2R/R2L asymmetry upgraded to CONFIRMED-BENIGN
    (gain 5.000/r2 1.000 both directions; it's the fixed-tag-aspect artifact, no bug).
    Not yet applied: HANDOFF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
    [model.sdf]
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2026-07-06 Tier-2 VERDICT + branch reconciliation: reject 60deg FOV, adopt streak=2 for fast regime
    ADR-0024 3rd addendum: the full FOV/streak sweep concluded.
    - 60deg FOV REJECTED (0/12 latch at 9 m/s — can't hold a fast crosser).
    - streak-min=2 (--early-handoff) ~DOUBLES 9 m/s latch (42%->88%, n=8) = the real
    acquisition fix; adopted for the fast/FPV regime (not yet global default,
    pending an S2-gate re-check).
    - 9 m/s MISS stays kinematic (~3.3 m) regardless — 3rd reconfirmation of ADR-0023.
    Reconciled the branch to a mergeable state: reverted the rejected 60deg config
    (shadow SDF removed, HANDOFF_RANGE 12->10, intrinsics back to wide fx=540, README
    FOV note rewritten as the documented nega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
    [model.sdf]
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2026-07-07 Demo FPV target model (drone carrying the AprilTag) + nicer demo-only world
    - models/fpv_target/: a quadcopter (SDF primitives, enemy look) that CARRIES the
    AprilTag — the tag plane is copied VERBATIM from apriltag_target (same pose/size/
    emissive_map, resolves the same texture asset) so detection is unchanged. Honest:
    the target is dressed as the drone it represents; the overlay states the AprilTag lock.
    - worlds/apriltag_demo.sdf: DEMO-ONLY world (gated worlds untouched) with nicer
    lighting/sky/ground + GUI chase-cam + VideoRecorder, placing the fpv_target.
    [apriltag_demo.sdf, model.sdf]
2026-07-07 Demo-video capture infra: world-name env-var fix, chase camera, capture tool
    - scripts/m2_detect.py, m4_target_mover.py, s2_cue_mock.py: add
    INTERCEPTOR_WORLD_NAME env-var override for the hardcoded WORLD_NAME =
    "apriltag" constant (default unchanged, byte-identical for every gated
    caller) — lets the same detector/mover/cue pipeline target
    worlds/apriltag_demo.sdf without forking any script. m4_intercept.py needed
    no edit (imports the topic constants, spawns mover/cue as subprocesses that
    inherit the env var). Needs an ADR-lite entry from the main session.
    - worlds/apriltag_demo.sdf: add a static chase/overview camera sensor
    (demo_chase_cam) for headless, scriptable 3rd-perso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
    [apriltag_demo.sdf]
2026-07-07 Demo video finished: hero intercept captured (1.06m clean), FPV reskin verified, chase-cam pose data-grounded
    Fixed a real XML-escaping bug that broke the x500_base interceptor reskin's
    model.config (unescaped <material>/<visual> in the description text); after
    the fix check_m2 PASSES with detection numbers unchanged (0.0858 m vs 0.0861 m
    baseline, within noise) - the reskin is confirmed visual-only.
    Re-derived the chase-camera pose from real hero-flight trajectory data
    (the two prior analytical guesses aimed ~12m short of the actual CPA point)
    and iterated it live against real rendered frames via gz service set_pose -
    no reboot needed per iteration. Final pose gives a level horizon with sk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
    [1345_prop_ccw.stl, 1345_prop_cw.stl, apriltag_demo.sdf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]
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2026-07-07 Demo polish: FPV drone re-orient + ground grid + honest track-viz + target-incoming (4 builder fixes)
    Drone body re-oriented to fly forward (tag plane preserved -> detection unchanged);
    ground grid texture (models/demo_ground_grid) for motion/speed reference; render_hud
    track-viz breaks at dropout gaps + smooth ground-truth reference; target incoming from
    start (trimmed capture). Refreshed sample frames. (Sonnet worker stalled mid-report;
    main session committed the on-disk result.)
    [apriltag_demo.sdf, model.sdf]
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2026-07-08 Portfolio currency pass + markerless target model (parallel to the M5 batch)
    Three sim-independent lanes, adversarially reviewed:
    - README.md: fixed both broken image embeds (pointed at committed docs/images stills,
    not gitignored artifacts), added ADR-0031 limitations row + ADR-0028 airframe-NULL
    finding, updated Demo to the shipped ADR-0032 assets, added the post-M5 roadmap
    section (bench -> markerless seeker -> EKF -> fusion capstone, ADR-0033/0034), and
    marked the in-progress final batch honestly (numbers pending, no fabrication).
    - docs/{WRITEUP,interviewer_prep,portfolio_bullets,portfolio_visuals}.md: forward-arc
    section, four new interview Q&As (fiducial-cheating/Kalman/fusi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
    [model.sdf]
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2026-07-08 Markerless seeker: combined venv + markerless world + entity-name params + mc_batch A/B knobs
    Post-M5 roadmap Option A infrastructure (fly the tag-less seeker; ADR-0033 item 2):
    - worlds/markerless.sdf: world "markerless" with the tag-less body fpv_target_markerless.
    - INTERCEPTOR_TARGET_MODEL env (default apriltag_target) parametrizes the gt/cue/mover/
    preplace target entity across m2_detect.py, s2_cue_mock.py, m4_target_mover.py,
    m4_intercept.py -- fixes gt-scoring + cue synthesis on the markerless world; apriltag
    path stays byte-identical.
    - mc_batch.sh: MC_WORLD / MC_TARGET_MODEL / MC_SEEKER / MC_VENV_PYTHON knobs (defaults =
    gated apriltag path). Solves ground_rig_sweep_plan.md'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
    [markerless.sdf, model.sdf]
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2026-07-09 T16 SHIPPED + verifier-gated: stereo rig world, capture harness, gate (ADR-0046)
    models/ground_stereo_rig: 2 static cameras, 2.0 m baseline (+-1.0 m poses),
    HFOV 0.349, 1920x1200@10Hz, RGB_INT8-default. worlds/stereo_intercept.sdf:
    markerless base (physics byte-identical, verifier-diffed) + rig at
    broadside_160m (-153.5, 0, 1.8, yaw 0 — 91%/91% corridor coverage both dash
    directions, wedge half-width ~28.2 m at 160 m standoff).
    rig_snapshot_capture.py: trajectory-matched teleport capture along the
    deterministic mover path (frozen-pose L/R = zero sync error, disclosed T23
    gap; gt columns capture-time-only, honesty note in docstring).
    check_t16.sh: 5-step gate — symlink, boot, both topics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
    [model.sdf, stereo_intercept.sdf]
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2026-07-10 Reproducibility (deep-audit H1): commit aggregate result CSVs + check_t21 gate
    The evidence base lived only in gitignored logs/ and the ADR-0058 headline
    (14/14 camera-terminal) had no scripted gate — a disk loss made the published
    numbers permanently unverifiable. Fixed:
    - .gitignore: logs/ -> logs/* (a ! exception cannot re-include a path inside a
    fully-ignored directory) + exceptions for the small aggregate result CSVs
    (mc_final_*, mc_t21_*, mc_realistic_*) and the 8 M3/M4 gate CSVs; per-tick
    flight CSVs, sim logs, ulogs, images stay ignored. 35 CSVs, ~574 KB.
    - scripts/check_t21.sh: re-runs analyze_track_ab.py on the committed r2 CSV
    and asserts the ADR-0058 three-way attributi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
    [m3_intercept_20260705T000619Z.csv, m3_intercept_20260705T000818Z.csv, m4_intercept_pronav_20260705T032238Z.csv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]
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2026-07-10 ADR-0059 comms-denied jam workstream: fail-closed fix (fail-safe) + 8-arm jam MC
    The overnight comms-denied validation, committed. Held too long uncommitted.
    - scripts/m4_intercept.py + detect_track.py: the cue-staleness fix (default-off,
    byte-identical when cue fresh; ages out a jammed/frozen cue -> camera-only
    fallback so the interceptor is not FOOLED into a phantom-handoff onto the stale
    cue). Double-reviewed (Fable), 86 tests pass.
    - tests/test_cue_staleness.py: 15 tests (honesty tripwire, staleness, inertness).
    - scripts/mc_jam_arm.sh: the 4-arm jam MC harness.
    - logs/mc_adr0059_*.csv: the 8 flown arms (control_strict/active + jam_fixoff/
    fixon at 15/18/22 m cutoffs).
    - docs/dec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
    [mc_adr0059_control_active.csv, mc_adr0059_control_strict.csv, mc_adr0059_jam_fixoff_r15.csv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]
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2026-07-10 logs: commit jink n=16 evidence (16/16, post-FIX-A) + remove 2 degenerate CSVs
    Jink n=16 on the adopted config, post-FIX-A: pooled 16/16 Pk@2.5, median 1.535 m
    (beats the pre-fix 15/16 jink baseline; tighter than the r2 weave headline).
    Closes FWD-A4's "post-fix jink re-run pending". ADR-0062 addendum records it.
    Removes two degenerate mc_t21 gitignore-exception files the audit tracker
    flagged (P-commitsE): mc_t21_trackgate_weave12.csv (invalid r1 arm, all 16
    miss_m=nan) and mc_t21_cuehandoff_jink12.csv (header-only) — both sat
    undistinguished next to the valid _r2 file.
    Claude-Session: https://claude.ai/code/session_017UphnogwrbUVvc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
    [mc_t21_cuehandoff_jink12.csv, mc_t21_trackgate_jink12.csv, mc_t21_trackgate_weave12.csv]
2026-07-10 ADR-0059 recovery = NULL (#39): --coast-search does not restore comms-denied
    The pre-registered recovery arm (fix + --coast-search) flew at the r18
    pre-acquisition jam (n=16). Coast-search ENGAGED (latch fired every jam flight,
    verified in run logs — not a plumbing no-op) but did NOT recover: REAL-ish
    handoffs 1/16 (need >=11; no-coast baseline 2/16), joint 1/16, never=12.
    Mechanism: on 10/16 flights the camera never reacquired during the coast+sweep
    (first_det empty, coverage ~0) — the guidance reached the basket but onboard
    PERCEPTION failed at the 15-21m coast range (far-range NN recall + the ADR-0060
    dash-pitch throwing the target above the down-pointed boresight; the lateral yaw
    swe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
    [mc_adr0059_jam_fixon_coast_r18.csv]
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2026-07-10 ADR-0064: Pk hardened to n=72 — >=95% (95% CI) at R=2.8m, 98.6% at 2.5m (#33)
    The resume-line Monte-Carlo backbone. Prior r2 n=16 only supported a 79.4% CP
    lower bound; FIX-A (ADR-0062) shipping mid-session made pooling with pre-FIX-A r2
    invalid, so flew a fresh homogeneous post-FIX-A weave campaign: 64 fresh flights
    (seeds 1042/2042/3042/4042) + 8 clean fixA_on = 72, adopted config, 12 m/s, one
    arm at a time at idle. Exact Clopper-Pearson (pure-Python binomial-tail bisection;
    neither venv has scipy). Result (pooled 72, median 1.784 m): Pk@2.8m 72/72 ->
    CP-LB 95.0% (the >=95%-CI bar); Pk@2.5m 71/72 = 98.6% point / 92.5% LB. The one
    sub-2.8m miss (2.757 m) handed off cleanly = terminal nois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
    [mc_pk72_weave_s1042.csv, mc_pk72_weave_s2042.csv, mc_pk72_weave_s3042.csv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]
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2026-07-10 ADR-0067: #35 up-tilt A/B FLOWN — FoV gap closes (32%->0% above-FoV) but gain is +2-3 m paired (interim +7.6 m was baseline-confounded) and uncompensated terminal cost is dose-dependent (Pk@2.5 8/8->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
    [mc_uptilt_weave12_up00.csv, mc_uptilt_weave12_up15.csv, mc_uptilt_weave12_up25.csv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]
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2026-07-10 #40 mount-compose RE-FLY FLOWN — Stage-1 verdict FAIL on strict parity (up15c worse 7/8), but compensation RECOVERED the terminal cost (Pk@2.5 4/8->8/8, median penalty +0.82->+0.16 m); NO fixed mount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
    Pre-registered re-fly (docs/adr0067_refly_preregistration.md, committed before
    the fly): up00 refly control vs up15 compensated, n=8 paired, master-seed 42.
    VALIDITY GATES: shadow swap TOOK (d(top_margin) +8.3 below +15 with d(first_det)
    +4.07 -- the review-corrected valid signature); machinery tripwire PASS (fresh
    refly-up00 reproduces the ADR-0067 up00 to sub-noise, miss med|d| 0.065 m); no-
    cheat audit (a)/(b) PASS + gt-leak (d) normal on every arm =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
    [mc_uptilt_refly_weave12_up00.csv, mc_uptilt_refly_weave12_up15c.csv]
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2026-07-10 #40 Stage-2 comms-jam RECOVERY re-test = NULL, and it RE-SCOPES the recovery limit from FoV-availability to FAR-RANGE NN DETECTION; "works comms-denied" STAYS HELD
    Pre-registered Stage-2 (docs/adr0067_refly_preregistration.md): the ADR-0059 #39
    coast-search jam arm re-flown r18/n=16 TILTED+COMPENSATED (up15 shadow +
    --cam-mount-up-deg 15). Coast-search VERIFIED engaged (12 stale-latches); tilt in
    all 16 flights.
    RESULT: RH (REAL-ish handoffs) 3/16 (need >=11 RECOVERY; #39 was 1/16 -> dRH +2 <
    the +4 PARTIAL floor) => NULL. MECHANISM (the load-bearing availability metric):
    camera-never-detected 12/16 (need <=4/16; #39 baseline 10/16) -- the tilt did NOT
    reduce never-detected. The 4 reacquisi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
    [mc_adr0059_jam_fixon_coast_r18_tilt15.csv]
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2026-07-11 #46 adaptive tilt BUILT (default-off, byte-identical): gimbal model + m4 own-state pitch-stabilization controller + live derotation
    The acquisition-range lever (ADR-0069): a pitch gimbal counters the nose-down dash
    to hold the seeker boresight near horizon, keeping the target in frame for EARLIER
    detection -> longer terminal t_go -> tighter miss.
    - MODEL scripts/experiments/gimbal_mount/x500_mono_cam/: the airframe with CameraJoint
    changed from FIXED to a CONTROLLED REVOLUTE PITCH joint + gz JointPositionController
    on /gimbal/pitch_cmd. Camera unchanged (1280x960, same intrinsics/topic) -> NN
    pipeline untouched. VALIDATED in sim (worker): boots, camera frames arrive, gimbal
    tracks c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
    [model.sdf]
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2026-07-11 ADR-0070: fixed-tilt + extended-handoff experiment FALSIFIES both the tilt and the "bigger t_go" premise — the ~1.5m miss is bearing-noise-floored (ADR-0056), not acquisition-limited
    3 paired arms (weave 12, n=8, master-seed 42, in-project #40 shadow, NO PX4 swap):
    - A2 (level + --handoff-range 15) doubled t_go (handoff 6.46->13.54m) but CPA UNCHANGED
    (paired median +0.016m, 4/8 each way) -> the extra terminal time bought nothing.
    - B (up15 tilt + comp + HO 15) is WORSE on 8/8 seeds vs level (+0.478m), and B-vs-A2
    (+0.539m, 7/8) proves it's the TILT, not the handoff knob.
    MECHANISM: the camera-only terminal is BEARING-NOISE-limited (~1.5m, ADR-0056: a clean
    AprilTag seeker already sits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
    [mc_tilt_A2_level_ho15.csv, mc_tilt_A_level.csv, mc_tilt_B_up15_ho15.csv]
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2026-07-11 Subpixel bearing n=8 SCREEN = the FIRST POSITIVE lever (ADR-0071) — paired mean -0.19m, wins big on the bad flights; n=16 extension in flight
    After accel-prediction (no), t_go/handoff-range (no), tilt (worse), the subpixel
    centroid bearing is the first lever to move the miss the right way. n=8 (level, weave
    12, master-seed 42): paired mean CPA -0.19m (A 1.55 -> B 1.36 on 7 valid pairs; seed0
    B was a MAVSDK offboard-race NaN, not subpixel), distribution median 1.85 -> 1.35 m,
    big wins on the high-miss flights (1.90->1.34, 1.06->0.70, 1.34->0.64), noise-level
    losses elsewhere. Delta-median flat (-0.001, 4/7 better) => promising-not-proven at
    n=7. Extending to ~n=16 (master-seed 43 pool). Evi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
    [mc_subpix_A_boxcenter.csv, mc_subpix_B_subpixel.csv]
2026-07-11 ADR-0071 A/B addendum: subpixel bearing WORKS (tail-concentrated) — pooled n=15, mean CPA -0.16m, worst-case miss 3.04->2.19m, Pk@2.5 14/15->15/15 (fixed a miss->kill)
    The FIRST positive lever after accel (no), t_go (no), tilt (worse). The win is
    TAIL-concentrated (the median is floored per ADR-0070), which is exactly right for
    the proximity-Pk metric. Evidence: master-seed 42+43 A/B CSVs. Extending to n~31
    (seeds 44/45) to confirm before the n=72 headline.
    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
    [mc_subpix_A_s43.csv, mc_subpix_B_s43.csv]
2026-07-11 ADR-0071 addendum #2: subpixel win was NOISE (n=31 mean flipped -0.16 -> +0.06); tighter-miss lane CLOSED — 2m is the seeker floor AND a proximity-fuse kill
    Extended the n=15 screen to n=31 (master-seeds 44+45): the promising mean regressed
    (n=15 -0.16m -> n=23 -0.075m -> n=31 +0.062m, sign 16 worse/11 better) -- small-sample
    noise. Marginal tail-only survivor (90th pctl 2.15 vs 2.40, Pk 30/31 vs 28/31) is within
    noise + B has a 7.66m outlier on a hard seed where A also fails (no handoff). Likely: the
    alpha-beta lambda filter already smooths the box-center jitter.
    DEFINITIVE: rigorously eliminated ALL levers for "2m is too much" -- accel (ADR-0069),
    t_go/handoff-range (ADR-0070), tilt (AD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
    [mc_subpix_A_s44.csv, mc_subpix_A_s45.csv, mc_subpix_B_s44.csv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]
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2026-07-11 New target: models/fpv_quad_enemy — a PROPER 3D quad (horizontal rotor plane, real x500 mesh, red enemy accents) + quad_enemy_verify world; render CONFIRMS it banks like a real drone
    Replaces the flat-billboard fpv_target_markerless (arms/props in the vertical Y-Z
    plane) with a genuine 3D quad: static, single link, 13 visuals (NXP frame + 4 motor
    bases + 4 red props + 4 red bells), rotor plane HORIZONTAL (props at local z~0.03-0.04),
    nose = +X. Meshes VENDORED into the repo as real files (clone-and-run; ~24 MB, of which
    the NXP airframe .dae is 22 MB — a git-LFS candidate when a GitHub remote is set up).
    gz sdf -k = Valid. fpv_target_markerless untouched.
    Chase render (worlds/quad_enemy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
    [1345_prop_ccw.stl, 1345_prop_cw.stl, model.sdf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]
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2026-07-11 retrain pipeline artifacts: worlds/quad_enemy.sdf (capture/intercept world w/ fpv_quad_enemy) + train_daemon_quad.py (detached YOLO fine-tune on the new-quad dataset)
    quad_enemy.sdf = markerless.sdf with the target swapped to fpv_quad_enemy (onboard
    cam, no chase). train_daemon_quad.py = train_daemon_v3.py retargeted to the quad_dataset
    (yolo11n, imgsz 640, 60 ep, setsid-detached, exports weights/drone_finetuned_quad.{pt,onnx},
    sentinel QUAD_TRAIN_EXPORT_DONE). The 1320-image gt-labeled dataset is gitignored
    (regenerable via render_sim_dataset.py). Deployed v2 + fpv_target_markerless untouched.
    Claude-Session: https://claude.ai/code/se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
    [quad_enemy.sdf]
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2026-07-12 ADR-0076 add #16: camera-mount move REMOVES the r2l phantom (validated) but needs a guidance lever-arm correction
    Builder directed testing the camera-move (extend past the props) instead of the
    retrain. Moved the seeker camera fwd 0.12->0.40m (swap PX4 stock model, restore
    after): rendered frames confirm NO props + target visible; v2 fires only the real
    target (25px @15m, correct range vs old 118-386px phantom). In flight,
    first_dash_detection 3.64->12-15m BOTH dirs -> real r2l target acquired early,
    phantom gone. BUT the guidance builds target=own_ned+range*LOS with no camera
    lever-arm, so the offset needed to clear props (>=0.2m) introduces a parallax that
    collapses BOTH dirs to the ~3.5m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
    [model.sdf]
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2026-07-15 real-build P0.3 (slice 1): extract portable flight/ core — geometry + coded-dash aim, 11 tests green
    Fable plan P0.3: pull the pieces that run IDENTICALLY in Gazebo SITL and on the real
    Pixhawk-6C/PX4 + Pi5 into a package with NO gz/gt/cue imports.
    flight/geometry.py -- wrap_pi, quat_rotate, euler_to_quat_body_to_ned,
    derotate_bearing_lambda (camera->body->NED LOS derotation,
    audit-3 H1 + #40 mount compose). Extracted VERBATIM from
    m4_intercept.py; legacy _quat_rotate/_euler_* aliases kept so
    m4 can import as a drop-in.
    flight/guidance.py -- collision_lead_heading: the coded-dash aim a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
    [geometry.py, guidance.py]
2026-07-15 ADR-0076 add #18 RESULT: coded-dash PAIRED A/B — r2l 0/8->5/8 @Pk (corrects interim over-claim)
    Paired A/B (quad_v2, seed 123, weave, n=8/dir, per-flight geometry verified byte-identical):
    eng clean Pk@2.5 miss_mean range
    CUE-GUIDED l2r 8/8 8/8 8/8 0.61 0.26-1.13
    CUE-GUIDED r2l 8/8 3/8 0/8 3.97 3.25-4.27
    CODED-DASH l2r 8/8 7/8 8/8 1.37 1.13-1.58
    CODED-DASH r2l 8/8 8/8 5/8 2.68 2.11-3.72
    HONEST correction of the mid-run '0/8 NULL -> 8/8 clean' I committed earlier: cue-guided r2l
    was NEVER a no-engagement null -- it ENGAGED 8/8 but at 3.25-4.27m, i.e. 0/8 inside the 2.5m
    Pk gate (that IS the saga's 'r2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
    [mc_coded_dash_qv2_weave.csv]
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2026-07-15 ADR-0076 add #18b: coded-dash ROBUSTNESS — tolerates +/-15deg aim error (16/16 acquire)
    +15deg heading-error sweep (paired weave/seed123/quad_v2, n=8/dir): every flight still
    ACQUIRES; l2r degrades 1.37->2.33m but stays 8/8 @Pk; r2l IMPROVES 2.68->1.60m (Pk 5/8->7/8)
    because +15deg biases its aim east, compensating the under-commit. Combined Pk@2.5m 13/16->
    15/16. Confirms the r2l residual is an east-aim deficit + a deliberate east-bias is a lever.
    Strong real-build viability evidence (the hand-programmed dash carries operator aim error).
    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
    [mc_coded_dash_qv2_weave_herr+15.csv]
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2026-07-15 real-build P0.3 (slice 3): extract flight/estimator.py — alpha-beta LOS/range tracker + Kalata
    The stateful estimator that runs the camera-only terminal's LOS-azimuth and range channels
    on the real Pixhawk/Pi -- AlphaBetaFilter (predict/correct, angular-residual wrap, rate-cap,
    opt-in Kalata adaptive gains) + kalata_alpha_beta, extracted VERBATIM from m4_intercept.py.
    Pure Python + math + flight.geometry.wrap_pi, no gz/gt/cue/loop deps. Same mirror pattern as
    geometry: m4 keeps its audited copy; test_estimator.py (6 tests: init, constant-velocity
    predict, angular wrap, rate-cap, Kalata gain-grows-with-gap, Kalata mode) pins the math.
    flight/ now holds geometry + coded-dash aim + estimator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
    [estimator.py]
2026-07-15 flight/guidance: add closing_speed + pronav_lateral_accel (a=N*Vc*lambda_dot) — core complete
    Rounds out the portable guidance core: flight/ now holds the LOS derotation (geometry),
    the alpha-beta LOS/range estimator (estimator), and the full guidance law (guidance: coded-
    dash collision-lead aim + closing-speed floor + the pro-nav command a=N*Vc*lambda_dot). 19
    tests. This is the complete camera-only-terminal math that runs on the real Pixhawk/Pi; the
    only non-portable remainder is the loop plumbing (gz frames, MAVSDK setpoints, v_perp/terminal
    -freeze bookkeeping) which is inherently host-specific.
    Claude-Session: https://claude.ai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
    [guidance.py]
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

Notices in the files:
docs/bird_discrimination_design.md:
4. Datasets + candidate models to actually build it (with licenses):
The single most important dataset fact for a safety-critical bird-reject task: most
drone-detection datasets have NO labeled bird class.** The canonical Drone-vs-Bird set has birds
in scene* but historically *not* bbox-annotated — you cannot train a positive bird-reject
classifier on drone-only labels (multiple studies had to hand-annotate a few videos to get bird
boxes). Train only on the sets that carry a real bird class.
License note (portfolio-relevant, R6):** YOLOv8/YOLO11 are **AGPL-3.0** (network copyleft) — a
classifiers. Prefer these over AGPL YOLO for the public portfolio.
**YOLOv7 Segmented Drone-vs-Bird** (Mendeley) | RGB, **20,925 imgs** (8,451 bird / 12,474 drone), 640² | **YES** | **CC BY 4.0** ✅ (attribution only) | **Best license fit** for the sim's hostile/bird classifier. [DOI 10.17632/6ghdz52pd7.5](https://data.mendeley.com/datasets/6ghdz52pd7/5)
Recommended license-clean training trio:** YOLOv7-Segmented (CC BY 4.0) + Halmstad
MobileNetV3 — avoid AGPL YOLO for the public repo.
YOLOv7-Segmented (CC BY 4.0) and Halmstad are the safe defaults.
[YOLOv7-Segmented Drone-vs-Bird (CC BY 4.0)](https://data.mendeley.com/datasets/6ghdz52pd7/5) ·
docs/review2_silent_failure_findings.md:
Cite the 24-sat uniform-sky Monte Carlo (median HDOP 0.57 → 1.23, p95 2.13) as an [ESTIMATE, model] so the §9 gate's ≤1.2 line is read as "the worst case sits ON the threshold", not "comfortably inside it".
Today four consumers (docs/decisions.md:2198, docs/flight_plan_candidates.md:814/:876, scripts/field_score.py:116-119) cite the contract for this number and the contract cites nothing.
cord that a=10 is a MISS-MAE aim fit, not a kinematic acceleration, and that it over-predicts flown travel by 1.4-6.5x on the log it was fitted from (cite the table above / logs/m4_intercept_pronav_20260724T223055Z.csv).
